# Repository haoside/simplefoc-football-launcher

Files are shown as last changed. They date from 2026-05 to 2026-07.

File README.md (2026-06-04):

# SimpleFOC Football Launcher

基于 SimpleFOC 的三无刷电机足球发射控制系统。

P0 目标：完成三路电机速度闭环、三轮同步预转、单次稳定射出标准 5 号足球，并具备基础安全保护。P0 明确为单球手动上球，不做多球管道/球仓/闸门。

## Project Goal

构建一套用于足球训练的三轮摩擦发射原型，通过三路 BLDC 独立调速与转速差控制，验证足球的速度、方向与旋转控制能力。

## P0 Scope

- 单电机 SimpleFOC 闭环稳定
- 三电机独立速度闭环
- 三轮同步预转
- 手动上球口 / 发射位球检测
- 单次稳定射出标准 5 号足球
- 急停 / 过流 / 堵转 / 过热保护
- 足球场地可移动底盘，电池供电优先
- 自动捡球接口预留（不实现机构）
- 面向专业足球运动员边路 `15~20m` 长传训练需求

## Out of Scope

- 自动瞄准
- 视觉识别
- 连续供球 / 多球仓 / 供球管道 / 闸门
- 自动捡球机构实现（仅预留接口）
- 高速发射
- 远程无人值守
- HA / Matter 接入

## Default Technical Direction

- 布局：`120° 均布三轮`
- 控制架构：`1 个上位控制板 + 3 个独立电机控制节点`
- 上位控制板：`ESP32-S3`
- 电机控制节点：`B-G431B-ESC1 ×3`
- Control Framework：`SimpleFOC`
- Motor：优先带 Hall 的 `6374 BLDC`，`170~190KV`
- Node 方案：P0-A 台架每个轮子 1 块 `B-G431B-ESC1`；P0-B 实球发射需切到高电流 SimpleFOC 驱动，不能把 B-G431B-ESC1 直接当最终动力板
- Feedback：P0 优先 Hall，增强方案可切 `AS5048A`
- Power：P0-A 低速台架按 `24V`；P0-B 现场按 `24V LiFePO4 40~60Ah` 与工程复核后的保护链路
- Control Target：P0 先做 `速度控制`

## P0 Milestones

1. 单电机闭环跑通
2. 三电机独立闭环跑通
3. 发射位球检测 + 发射状态机跑通
4. 单次低速稳定射球
5. 故障保护停机

## Suggested Repository Layout

```text
/docs
  P0_TECH_PLAN.md
  BOM_DRAFT.md
  INTERFACES.md
  CONNECTION_SCHEME.md
  CONNECTION_DIAGRAM.md
  FIRMWARE_MODULES.md
/firmware
  common/
  host-esp32s3/
  motor-node-g431/
/hardware
  README.md
  host-esp32s3/
  motor-node-g431/
  PCB_RULES.md
  HOST_PCB_LAYOUT.svg
  MOTOR_NODE_PCB_LAYOUT.svg
```

## Safety

> 该项目涉及高速旋转部件和射出机构，P0 仅允许低速测试。

- 必须先做低速测试
- 发射方向禁止站人
- 必须有物理急停按钮
- 必须安装摩擦轮防护罩
- 默认上电即安全空闲态
- 无人看护时禁止运行

## Status

当前阶段：`P0 方案冻结 / 硬件与固件拆分中`

## Bring-up

- `docs/FIRMWARE_BRINGUP_PLAN.md`
- `docs/FIRMWARE_BRINGUP_CHECKLIST.md`

- `docs/CAN_PROTOCOL_V1.md`
- `docs/FIRMWARE_COMM_LOOP.md`
- `docs/NODE_CONTROL_CHAIN.md`
- `docs/HOST_CONTROL_CHAIN.md`
- `docs/FAULT_SAFETY_CHAIN.md`
- `docs/HAL_ADAPTER_PLAN.md`
- `docs/HAL_INTEGRATION_STATUS.md`
- `docs/NODE_HAL_DATA_FLOW.md`
- `docs/PLATFORM_TEMPLATE_PLAN.md`
- `docs/HOST_TELEMETRY_V1.md`
- `docs/ARCH_DECISION_BG431B_ESC1.md`
- `docs/CODEGEN_SINGLE_BALL_HOST_V1.md`
- `docs/CODEGEN_BG431B_NODE_V1.md`
- `docs/BG431B_NODE_INSTANTIATION_V1.md`
- `docs/HOST_3NODE_INTEGRATION_DEMO_V1.md`
- `docs/DEBUG_GUIDE_V1.md`
- `docs/NODE_DEBUG_OUTPUT_V1.md`
- `docs/HOST_DEBUG_COMMANDS_V1.md`
- `docs/CURVE_BALL_CONTROL_V1.md`
- `docs/HOST_DEBUG_WHEEL_JOG_V1.md`
- `docs/PRACTICAL_CURVE_PASS_PRESETS_V1.md`
- `docs/SHORT_GUIDE_TUBE_V1.md`
- `docs/HOST_PRESET_COMMANDS_V1.md`
- `docs/SHORT_GUIDE_TUBE_TEST_MATRIX_V1.md`
- `docs/P0_AB_TEST_LOG_TEMPLATE_V1.md`
- `docs/ENVIRONMENT_SIM_PARAMS_V1.md`
- `docs/ENVIRONMENT_SIM_TEST_MATRIX_V1.md`
- `docs/P0_FIELD_TEST_LOG_TEMPLATE_V2.md`
- `docs/sim/ENVIRONMENT_TUNING_RECOMMENDATIONS_V1.md`
- `docs/HOST_WIND_PRESETS_V1.md`
- `docs/HOST_ENV_PROFILES_V1.md`
- `docs/HOST_ENV_COMMANDS_V1.md`
- `docs/HOST_ENV_PRESET_COMMAND_MATRIX_V1.md`
- `docs/OPERATOR_QUICK_CARD_V1.md`
- `cad/3d-print/short-guide-tube-v1/short_guide_tube_v1.scad`
- `docs/mechanical/SHORT_GUIDE_TUBE_DRAWING_V1.md`
- `cad/sheet-metal/motor-mount-plate-v1/motor_mount_plate_v1.scad`
- `docs/mechanical/MOTOR_MOUNT_PLATE_DRAWING_V1.md`
- `docs/mechanical/CAD_EXPORT_GUIDE_V1.md`
- `docs/mechanical/MANUFACTURING_PRIORITY_V1.md`
- `docs/mechanical/PRE_FAB_CHECKLIST_V1.md`
- `docs/mechanical/EXPORT_FILE_CHECKLIST_V1.md`
- `docs/mechanical/FILE_VERSION_MATRIX_V1.md`

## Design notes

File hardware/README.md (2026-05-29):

# Hardware Design Package v1

当前仓库已补硬件设计基线，用于进入原理图与 PCB 设计阶段。

## 文件
- `host-esp32s3/HOST_SCHEMATIC.md`
- `motor-node-g431/MOTOR_NODE_SCHEMATIC.md`
- `host-esp32s3/HOST_COMPONENT_LIST.md`
- `motor-node-g431/MOTOR_NODE_COMPONENT_LIST.md`
- `motor-node-g431/MOTOR_NODE_SUBCIRCUITS.md`
- `PCB_RULES.md`
- `HOST_PCB_LAYOUT.svg`
- `MOTOR_NODE_PCB_LAYOUT.svg`
- `pinout/HOST_PINOUT.md`
- `pinout/MOTOR_NODE_PINOUT.md`
- `pinout/CONNECTOR_TABLE.md`
- `pinout/HOST_NETS.csv`
- `pinout/MOTOR_NODE_NETS.csv`
- `host-esp32s3/HOST_NET_BY_NET.md`
- `motor-node-g431/MOTOR_NODE_NET_BY_NET.md`
- `PCB_LAYOUT_CONSTRAINTS.md`
- `host-esp32s3/HOST_SCHEMATIC_PAGES.md`
- `motor-node-g431/MOTOR_NODE_SCHEMATIC_PAGES.md`
- `SCHEMATIC_PAGE_INTERFACES.md`
- `host-esp32s3/HOST_FOOTPRINT_GUIDE.md`
- `motor-node-g431/MOTOR_NODE_FOOTPRINT_GUIDE.md`
- `FIRST_SPIN_BRINGUP.md`

## 当前设计策略
- Host 与 Motor Node 分板
- Motor Node 一板一电机
- CAN 作为 Host ↔ Node 总线
- 24V P0 联调，预留 36V 升级
- 急停硬件切驱动使能/主回路

## 下一步
1. 按上述网表与接口在 KiCad 建原理图
2. 先完成 Host 板与单个 Motor Node 板
3. 用单电机闭环先验证功率级与 Hall 反馈

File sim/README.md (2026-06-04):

# P0 Simulation: 3-BLDC Football Launcher

## Goal

Validate the first-order mapping:

```text
wheel1/2/3 RPM -> launch speed / spin / curve / landing point
```

This is a lightweight numerical model for parameter screening. It is not CFD, FEA, or final system validation.

## Frozen geometry

- 3 friction wheels in 120° distribution
- wheel1 @ 12:00
- wheel2 @ 4:00
- wheel3 @ 8:00
- standard size-5 football: 0.22 m diameter, 0.43 kg
- nominal wheel diameter: 0.11 m

## Run

```bash
python3 sim/football_launch_model.py
```

## Outputs

- recommended wheel RPMs for:
  - straight pass
  - light curve assist pass
  - standard curve assist pass
- estimated launch speed
- estimated spin rate
- estimated range and lateral offset
- rough current risk flag based on RPM/ramp

## Calibration needed on real machine

1. Actual wheel surface speed vs. measured ball exit speed.
2. Effective friction coefficient for wheel rubber + football surface.
3. Best preload window between 5–15 mm.
4. Actual curve strength vs. `spinBiasRpm`.
5. Current peak during 4/5/6 s spin-up ramps.

## P0 acceptance use

Use the model to choose first safe RPM presets before field tests. Then update the model constants from measured data.

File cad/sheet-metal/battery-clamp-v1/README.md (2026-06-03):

# Battery Clamp v1

## Purpose
Retaining top clamp for 24V LiFePO4 battery in lower bay.

## Key dimensions
- Strap plate: 260 mm x 35 mm x 4 mm
- Mount holes: 2 x 6.0 mm
- Center relief slot: 120 mm x 12 mm
- Material: 5052 / 6061, 4 mm

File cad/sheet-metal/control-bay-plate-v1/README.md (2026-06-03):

# Control Bay Plate v1

## Purpose
Mounting plate for ESP32-S3, three B-G431B-ESC1 nodes, and CAN/terminal area.

## Key dimensions
- Plate: 250 mm x 180 mm x 4 mm
- Corner mount holes: 4 x 5.5 mm
- Board standoff holes: mixed 3.2 mm / 4.0 mm provisional
- Material: 5052 / 6061, 4 mm

## Notes
- Hole positions are provisional for P0 packaging.
- Must be rechecked against actual B-G431B-ESC1 board outline after purchase.

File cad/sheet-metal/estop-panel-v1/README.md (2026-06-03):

# E-Stop Panel v1

## Purpose
Front-right mounting panel for emergency stop button.

## Key dimensions
- Plate: 100 mm x 80 mm x 3 mm
- E-stop hole: 22.5 mm
- Mount holes: 4 x 5.0 mm
- Material: 5052 / 6061, 3 mm

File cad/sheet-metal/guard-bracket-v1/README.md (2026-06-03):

# Guard Bracket v1

## Purpose
Flat bracket set for supporting the transparent PC guard cover.

## Key dimensions
- Main bracket plate: 220 mm x 40 mm x 4 mm
- Mount holes: 4 x 5.5 mm
- Guard holes: 3 x 4.5 mm
- Material: 5052 / 6061, 4 mm

## Notes
- P0 favors flat-plate manufacturability first.
- Final bend / standoff strategy may be added after frame spacing is confirmed.

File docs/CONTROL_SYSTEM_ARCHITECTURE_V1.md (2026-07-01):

# 控制系统架构 V1 — 车载显示器 + 控制器

> 状态：V1 初版
> 作者：全栈工程师
> 触发：PM 重新分配任务（2026-07-01）
> 关联：DISPLAY_UI_WIREFRAME_V1（设计师交付）
> 目标：可落地的车载人机控制方案，不只是展示图

---

## 0. 范围与边界

**包含**：
- 主控硬件选型（3 档对比）
- 显示器、摄像头、电机控制、推进控制、电源
- 软件模块划分
- 屏幕显示字段
- 控制输入设计
- 数据流 + MVP 清单

**不包含**（后续 V2+）：
- 具体 PCB 设计
- 真实 Gazebo / 仿真环境
- 安全认证（CE/UL）
- 详细成本报价

---

## 1. 硬件架构

### 1.1 主控选型（三档对比）

| 维度 | ESP32-S3 | Raspberry Pi 4B | Jetson Nano |
|---|---|---|---|
| CPU | Xtensa LX7 双核 240 MHz | Cortex-A72 4 核 1.5 GHz | Cortex-A57 4 核 1.43 GHz + 128 CUDA |
| RAM | 512 KB SRAM + 8 MB PSRAM | 4 GB LPDDR4 | 4 GB LPDDR4 |
| 实时性 | ⭐⭐⭐ 硬实时 | ⭐⭐ 软实时（Linux） | ⭐⭐ 软实时（Linux）|
| 视觉推理 | ❌ 跑不动 ML | ⭐⭐ 基础 CNN/TF-Lite | ⭐⭐⭐ GPU 推理 |
| 视频输入 | 1× 摄像头 (小分辨率) | 2× CSI / USB | 2× CSI / USB |
| 显示器输出 | SPI/8080（小型）| HDMI 2× | HDMI + DP |
| 功耗 | 0.5 W | 5 W | 10 W |
| 价格 | ¥20 | ¥300 | ¥800 |
| 实时控制 3× 电机 | ⭐⭐⭐ 直接 PWM | ⭐⭐ 需要 RT-PREEMPT | ⭐⭐ 需要 RT-PREEMPT |
| **MVP 推荐** | ✅ **选这个** | 备选 | 长期升级 |

**MVP 选 ESP32-S3**：
- 硬实时满足 3 电机 1kHz 控制环
- 功耗低、发热少、车载电池友好
- 摄像头 + 视觉推理可通过外接 USB 摄像头 + 上传至云/手机
- 显示器接 SPI 5寸触摸屏（够用）

**长期升级路径**：
- ESP32 → Pi 4B（加本地视觉）
- Pi 4B → Jetson Nano（加 GPU 视觉）

### 1.2 显示器

| 选项 | 规格 | 优势 | 劣势 |
|---|---|---|---|
| **5 寸 HDMI 触屏** | 800×480 | 便宜、体积小 | 户外可视性一般 |
| 7 寸 HDMI 触屏 | 1024×600 | 大、信息多 | 体积大 |
| 7 寸高亮屏 | 1000 nits | 户外强光可读 | 贵、发热大 |
| **车载工业屏** | 7-10 寸，IP65 | 抗振防水 | ¥2000+ |

**MVP 选 5 寸 HDMI 触屏**（¥80-150）+ 遮光罩（户外）。

### 1.3 摄像头

| 方案 | 用途 | FPS | 延迟 |
|---|---|-----|---|
| USB 摄像头 (Logitech C270 等) | 球路捕捉 | 60 | 50 ms |
| Pi CSI 摄像头 (IMX219) | 球路捕捉 + 嵌入式 | 30 | 30 ms |
| 工业相机 (FLIR/Point Grey) | 高速捕捉 | 120+ | <10 ms |
| **手机 + WiFi 上传** | 慢速捕捉 | 30 | 200 ms |

**MVP 选 USB 摄像头**（最便宜、足够 MVP 验证）。

### 1.4 电机控制（3 路）

| 部件 | 选型 |
|---|---|
| 电机 | 3× 6374 BLDC（外转子当滚轮）|
| 驱动器 | 3× **SimpleFOC B-G431B-ESC1**（已选）|
| 通信 | SPI 或 CAN 总线 → 主控 ESP32 |
| 编码器 | AS5048A 磁编码器（已选）|
| 闭环 | FOC 扭矩/速度环，1 kHz |

**理由**：SimpleFOC 是项目已选方案，硬件 BOM 已确定，V1 沿用。

### 1.5 推进控制（气压主线）

| 部件 | 选型 |
|---|---|
| 气源 | 8 bar 压缩机 或 20L 钢瓶 |
| 储气罐 | 5-20L 不锈钢（带爆破片）|
| 电磁阀 | 12V 大流量两位三通阀（响应 <30 ms）|
| 压力传感器 | 0-1 MPa 模拟输出 |
| 阀门 | 手动截止阀（安全）|
| 爆破片 | 1.2× 工作压力（10 bar）|
| 泄压阀 | 1.1× 工作压力（9 bar）|
| 球挡位置 | 红外对射传感器（检测球到位）|

### 1.6 电源

| 用电器 | 电压 | 电流 | 电源 |
|---|---|---|---|
| 主控 ESP32 | 5V | 0.5A | 5V DC-DC |
| 显示器 | 12V | 1A | 12V DC-DC |
| 3× ESC | 12-24V | 3× 30A 峰值 | 锂电池 24V |
| 电磁阀 | 12V | 1A | 12V DC-DC |
| USB 摄像头 | 5V | 0.5A | 5V |
| 风扇（散热）| 12V | 0.2A | 12V |

**主电源**：24V 锂电池组（10Ah 起）→ DCDC 隔离
- 控制电源（5V/12V）与动力电源（24V）**物理隔离**
- 加 TVS 防浪涌、保险丝

---

## 2. 软件模块

### 2.1 模块划分

```text
control_system/
├── main/                # 主控 ESP32 固件
│   ├── main.cpp         # FreeRTOS 主循环
│   ├── motor_ctrl.cpp   # 3× FOC 闭环控制
│   ├── valve_ctrl.cpp   # 电磁阀 + 压力传感器
│   ├── safety.cpp       # 急停 / 互锁
│   └── comm.cpp         # CAN/SPI 主从通信
├── vision/              # 视觉（Pi 或 ESP32-S3 USB）
│   ├── capture.cpp      # 摄像头采集
│   ├── track.cpp        # 球路识别（OpenCV）
│   └── predict.cpp      # 轨迹预测
├── ui/                  # 显示器界面（PyQt 或 LVGL）
│   ├── main_screen.py   # 主控首页
│   ├── arc_screen.py    # 弧线模拟页
│   ├── param_screen.py  # 参数调节页
│   └── diag_screen.py   # 诊断页
├── comm/                # 主从通信协议
│   ├── can_proto.md     # CAN 消息定义
│   └── serial_proto.md  # 串口消息定义
├── config/              # 配置
│   ├── mvp_params.yaml  # MVP 默认参数
│   └── presets/         # 发射预设
└── sim/                 # 仿真接口
    ├── trajectory.py    # 轨迹计算
    └── mux.py           # 3 电机混合
```

### 2.2 主控 ESP32 任务（FreeRTOS）

```c
// 任务优先级（数字越大越高）
void setup() {
  // Task 1: 电机控制循环 1kHz，优先级 10
  xTaskCreate(motor_ctrl_loop, "motor", 4096, NULL, 10, NULL);
  // Task 2: 阀门触发（紧急），优先级 12
  xTaskCreate(valve_trigger, "valve", 2048, NULL, 12, NULL);
  // Task 3: 通信接收，优先级 8
  xTaskCreate(comm_rx, "comm", 2048, NULL, 8, NULL);
  // Task 4: 安全监控，优先级 15（最高）
  xTaskCreate(safety_monitor, "safety", 1024, NULL, 15, NULL);
  // Task 5: 状态上报，优先级 5
  xTaskCreate(status_report, "status", 2048, NULL, 5, NULL);
}
```

### 2.3 显示器 UI（PyQt / LVGL）

**MVP 选 LVGL**（轻量，可在 ESP32-S3 上直接跑）：
- C 语言，资源占用小
- 支持触摸屏
- 可在 Pi 上用 Python binding

**完整版可换 PyQt**（在 Pi 4B 上）：
- Python 生态丰富
- 集成 OpenCV 视觉处理

### 2.4 视觉处理（轨迹捕捉）

```python
# vision/track.py 伪代码
def detect_ball_in_frame(frame):
    """在单帧中检测球位置（HSV 阈值 + 轮廓）"""
    hsv = cv2.cvtColor(frame, cv2.COLOR_BGR2HSV)
    mask = cv2.inRange(hsv, BALL_HSV_LOW, BALL_HSV_HIGH)
    contours, _ = cv2.findContours(mask, ...)
    if contours:
        largest = max(contours, key=cv2.contourArea)
        return cv2.minEnclosingCircle(largest)
    return None

def track_trajectory(frames):
    """从多帧提取球位置，滤波后输出轨迹"""
    positions = []
    for f in frames:
        p = detect_ball_in_frame(f)
        if p:
            positions.append(kalman_filter(p))
    return fit_parabola(positions)
```

---

## 3. 屏幕显示内容（与 UI Wireframe 对齐）

### 3.1 主控首页字段

| 字段 | 数据源 | 刷新率 |
|---|---|---|
| `mode` | 用户选择 | 触发时 |
| `launch_ready` | 状态机 | 100 ms |
| `safety_locked` | 物理急停 + 软件锁 | 10 ms |
| `emergency_stop` | GPIO + 软件 | 10 ms |
| `battery_percent` | ADC | 1 s |
| `battery_voltage` | ADC | 1 s |
| `temperature` | DS18B20 | 5 s |
| `pressure` | 模拟输入 | 100 ms |
| `propulsion_type` | 配置文件 | 启动时 |
| `valve_delay_ms` | 实测 | 1 s |
| `piston_force` | 编码器 | 100 ms |
| `motor_a/b/c_rpm` | FOC 反馈 | 100 ms |
| `motor_a/b/c_temp` | NTC | 1 s |
| `camera_status` | OpenCV | 1 s |
| `camera_fps` | 帧率计数器 | 1 s |
| `vision_confidence` | 检测分数 | 100 ms |

### 3.2 弧线页字段

| 字段 | 公式/来源 |
|---|---|
| `predicted_landing_x` | 物理模型（g, v0, angle）|
| `predicted_landing_y` | 物理模型 + Magnus |
| `actual_landing_x` | 视觉检测（球落点像素 → m）|
| `actual_landing_y` | 视觉检测 |
| `distance_error` | abs(pred - actual) |
| `lateral_error` | abs(pred_y - actual_y) |
| `landing_zone_heatmap` | 历史落点 2D 直方图 |
| `wind_estimate` | 多帧位移 → 速度差 |

### 3.3 参数页字段

| 参数 | 范围 | 单位 | 默认 |
|---|---|---|---|
| `motor_a_rpm` | 0-5000 | rpm | 2500 |
| `motor_b_rpm` | 0-5000 | rpm | 2500 |
| `motor_c_rpm` | 0-5000 | rpm | 2500 |
| `pressure` | 0-10 | bar | 8 |
| `valve_delay` | 0-100 | ms | 12 |
| `piston_force` | 0-100 | % | 75 |
| `curve_strength` | -50 to +50 | % | 0 |
| `topspin_strength` | -50 to +50 | % | 0 |

### 3.4 诊断页字段

| 字段 | 含义 | 颜色 |
|---|---|---|
| `system_status` | 整体 | 绿/黄/红 |
| `motor_a_temp` | 电机温度 | 绿<60°C / 黄<80°C / 红>80°C |
| `motor_rpm_drift` | RPM 偏差 % | <5%绿 / <10%黄 / >10%红 |
| `pressure_leak` | 压降速率 bar/s | <0.05 绿 |
| `valve_response_ms` | 阀门开闭时间 | <30 绿 |
| `battery_voltage` | 电池电压 | >22V 绿 |
| `cpu_temp` | 主控温度 | <70°C 绿 |
| `system_errors[]` | 错误码列表 | 详情面板 |

---

## 4. 控制输入

### 4.1 输入方式

| 输入 | 用途 | 优先级 |
|---|---|---|
| 触摸屏 | 主要调节 | MVP |
| 实体旋钮 ×2 | 备用调节（戴手套） | 第二阶段 |
| 物理急停按钮 | 安全（硬急停） | **必须** |
| 物理模式旋钮 | 模式快速切换 | MVP |
| 手柄/遥控 | 远距离发射 | 可选 |
| 语音 | 解放双手 | 不推荐（噪音） |

### 4.2 安全互锁

```c
// 发射触发前必检
bool launch_check() {
    return pressure_ok()        // 气压 ≥ 设定值 ±5%
        && motors_synced()      // 3 电机 RPM 在 ±5% 范围
        && ball_loaded()        // 球挡传感器触发
        && safety_unlocked()    // 物理解锁
        && !emergency_stop()    // 急停未触发
        && camera_ready()       // 摄像头就绪
        && no_errors();         // 无系统错误
}
```

### 4.3 急停链路

```text
[物理急停] → [硬件切断电磁阀电源]
         → [GPIO 中断到主控]
         → [电机控制 0 PWM]
         → [UI 全屏红色]
         → [需人工复位]
```

**急停是硬切断**，不依赖软件。

---

## 5. 数据流图

```text
                       视觉捕捉
                          ↓
  摄像头 → Pi/Jetson ──→ 落点检测
       (USB/CSI)         ↓
                    实际落点 (x,y)
                          ↓
  物理参数 ───→  仿真引擎  ───→  预测落点
  (RPM, 压力)    (Python)        (x,y)
                          ↓
                  偏差 = 实际 - 预测
                          ↓
                  ┌────────┴────────┐
                  ↓                 ↓
              UI 显示          参数回填
          (车载显示器)    (推荐新 RPM/压力)
                              ↓
                          ESP32 主控
                              ↓
              ┌───────┬───────┬───────┐
              ↓       ↓       ↓       ↓
            电机 A  电机 B  电机 C  电磁阀
              (6374) (6374) (6374)   (气压)
              ↓       ↓       ↓       ↓
            can    can    can    球被发射
              └───────┴───────┘
                  ↓
                 球
```

---

## 6. MVP 版本清单

### 6.1 MVP V1.0（4 周内）

| 项目 | 描述 | 状态 |
|---|---|---|
| 硬件 | ESP32-S3 + 3× ESC + 5寸触屏 + USB 摄像头 | 采购 |
| 控制 | 3 电机 1kHz 闭环 + 阀门触发 | 实现 |
| 安全 | 物理急停 + 气压互锁 | 实现 |
| UI | LVGL 4 屏（首页/弧线/参数/诊断）| 实现 |
| 视觉 | 球路捕捉（简单阈值）| 简化 |
| 通信 | USB 串口（PC 调试）| 简化 |

### 6.2 V1.1（4-8 周）

- Pi 4B 替代 ESP32-S3（加本地视觉）
- 完整 4 屏 UI（PyQt）
- 历史发射记录数据库
- 预设管理

### 6.3 V2.0（8-12 周）

- Jetson Nano 升级
- 完整视觉推理（球速、落点预测）
- 自动参数校正
- 多发射器联网管理

---

## 7. 验收标准

按 PM 要求：

| 标准 | 回答 |
|---|---|
| 1. 人怎么操作 | 触摸屏 + 旋钮 + 急停。模式按钮 → 确认 → 装球 → 发射。详情见 UI Wireframe |
| 2. 机器怎么执行 | ESP32 → FOC ESC → 3 电机 + 电磁阀。闭环 1kHz。阀门响应 <30ms |
| 3. 球路怎么被预测/反馈 | 物理模型（抛物 + Magnus）预测 + 摄像头识别实际 → 偏差 → UI |
| 4. 异常怎么停机 | 物理急停硬切断 + 软件互锁 → 全屏红 → 诊断页 → 复位 |
| 5. 切回推进结构 | 气压主线（轴向）+ 三电机控旋，控制器对应有 推进源切换 + 三电机 RPM 控制 |

---

## 8. 与 UI Wireframe 的接口

按设计师 `DISPLAY_UI_WIREFRAME_V1` 的字段清单：

```python
# ui/interface.py 字段
@dataclass
class UIData:
    # Mode
    mode: str                           # "STRAIGHT" / "LEFT_CURVE" / ...
    launch_ready: bool
    safety_locked: bool
    emergency_stop: bool

    # Pressure
    pressure_mpa: float
    propulsion_type: str                # "pneumatic" / "tangent_friction"
    valve_delay_ms: float
    piston_force_pct: float

    # Motors
    motor_a_rpm: int
    motor_b_rpm: int
    motor_c_rpm: int
    motor_a_temp_c: float
    motor_b_temp_c: float
    motor_c_temp_c: float

    # Vision
    camera_status: str                  # "OK" / "ERROR" / "OFFLINE"
    camera_fps: float
    vision_confidence: float

    # Trajectory
    predicted_landing_x: float
    predicted_landing_y: float
    actual_landing_x: float
    actual_landing_y: float
    distance_error_m: float
    lateral_error_m: float

    # Power
    battery_percent: float
    battery_voltage: float
    system_errors: list[str]
```

主控（ESP32）和 UI（Pi 屏）通过 CAN 或 USB 串口交换 UIData。

---

## 9. 已知风险

| 风险 | 缓解 |
|---|---|
| ESP32 算力不够视觉 | MVP 用 USB 摄像头 + Pi 远端处理 |
| 5 寸屏户外可读性差 | 加遮光罩，后期换 7寸高亮 |
| 锂电池振动/温度 | 用工业级电池（带 BMS）|
| 电磁阀误触发 | 双路阀门 + 物理急停 + 软件互锁 |
| 视觉识别误判 | 加置信度阈值，低置信度禁用发射 |
| 急停响应时间 | 物理急停硬切断 < 10ms |

---

## 10. 交付物

- ✅ 本文档 `CONTROL_SYSTEM_ARCHITECTURE_V1.md`
- ⏭ `MVP_PARAMS_V1.yaml`（默认参数）
- ⏭ `CAN_PROTOCOL_V1.md`（如果需要）
- ⏭ `comm.proto`（主从通信协议）
- ⏭ `safety_checklist.md`（安全清单）

---

## 11. 变更日志

- V1：初版，2026-07-01，按 PM 重新分配任务交付

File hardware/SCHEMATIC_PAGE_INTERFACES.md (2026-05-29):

# 原理图分页页间接口表 v1

## Host 板页间接口
| Page | Export Nets |
|---|---|
| H1 Power | `VIN_24V`, `+5V`, `+3V3`, `PGND`, `GND` |
| H2 ESP32 Core | `CAN_TX`, `CAN_RX`, `SIG_TUBE`, `SIG_CHAMBER`, `SIG_EXIT`, `SIG_ESTOP`, `PWM_FEED`, `FEED_DIR`, `LED_STATUS`, `BUZZER_CTL`, `UART0_TX`, `UART0_RX` |
| H3 CAN/Debug | `CAN_H`, `CAN_L` |
| H4 Sensors | 输入页，主要消费传感器信号 |
| H5 Feed/Indicators | 执行器与指示器页 |

## Motor Node 板页间接口
| Page | Export Nets |
|---|---|
| M1 Power | `VIN_24V`, `VDRV`, `+3V3`, `PGND`, `AGND`, `GND` |
| M2 MCU Core | `PWM_U`, `PWM_V`, `PWM_W`, `DRV_EN`, `DRV_FAULT_N`, `HALL_A`, `HALL_B`, `HALL_C`, `ISENSE_A`, `ISENSE_B`, `VBUS_SENSE`, `TEMP_SENSE`, `CAN_TX`, `CAN_RX`, `SWDIO`, `SWCLK`, `NRST` |
| M3 Gate Driver | `GH_U/GL_U`, `GH_V/GL_V`, `GH_W/GL_W`, `SH_U`, `SH_V`, `SH_W` |
| M4 Power Stage | `PHASE_U`, `PHASE_V`, `PHASE_W`, `ISENSE_A`, `ISENSE_B` |
| M5 Sense | Hall / VBUS / TEMP 感知页 |
| M6 CAN | `CAN_H`, `CAN_L` |

## 命名规则
- 页间全局网统一用大写下划线风格
- 功率网与逻辑网不要混名
- `PGND / AGND / GND` 明确分开，单点策略在 PCB 实现

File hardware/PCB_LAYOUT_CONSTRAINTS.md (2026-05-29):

# PCB 布局关键约束 v1

## Host 板
### 1. 电源
- 24V 输入、保险、TVS、DCDC 放在板边同一区域
- Buck 高 di/dt 回路尽量小
- 5V 与 3.3V 分区明显

### 2. MCU / 通信
- ESP32-S3 天线朝外，周围净空
- CAN 收发器靠近 CAN 接口
- 调试口靠板边

### 3. 传感器 / 执行器
- 传感器口成排放置，便于线束
- 舵机/闸门驱动靠近接口，避免大电流绕行 MCU
- 急停反馈与状态灯放近边缘便于维护

## Motor Node 板
### 1. 功率区优先
- `VIN_24V -> DC Link -> Half Bridge -> Motor Connector` 路径最短
- Gate Driver 紧贴 MOSFET
- Bootstrap 电容紧贴 Driver 脚位

### 2. 采样优先
- Shunt Kelvin 采样单独引出
- `VBUS_SENSE` 远离开关节点
- 模拟采样线不穿越相线区

### 3. 控制 / 通信
- STM32G431 放在 Driver 边缘但远离功率热区
- CAN 收发器靠近接口
- SWD 靠板边
- Hall 接口远离三相输出端子

### 4. 热与机械
- MOSFET 散热铜皮充分
- 功率区预留散热片/风道空间
- 电机三相接口用大焊盘、大电流端子
- 板安装孔避免穿过敏感回流路径

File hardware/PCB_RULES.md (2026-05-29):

# PCB 设计规则 v1

## 1. 分板建议
- **Host 板** 与 **Motor Node 板** 分开
- 不做三路一体功率板，P0 先以可调试、可替换为优先

## 2. Host 板
- 建议 4 层：`Signal / GND / 3V3_5V / Signal`
- 传感器与 CAN 靠近连接器放置
- DCDC 与 ESP32 天线区隔离
- 天线下方与前方保持净空

## 3. Motor Node 板
- 建议 4 层起步：`Signal / GND / Power / Signal`
- 功率回路最短：MOSFET、Driver、Shunt 紧凑布置
- Hall、CAN、SWD 远离三相开关节点
- 模拟采样地与功率地单点汇接
- 母线电容紧贴功率级

## 4. 关键布局约束
- Driver 到 MOSFET Gate 走线短且对称
- Shunt 到 ADC/放大器 Kelvin 引出
- VBUS 分压靠近 MCU ADC 输入并加 RC 滤波
- FAULT/ENABLE 线远离相线
- CANH/CANL 差分并行走线

## 5. 安全
- 24V 输入、功率级、逻辑区明确分区
- 预留测试点：3V3、5V、24V、VBUS_SENSE、ISENSE、FAULT、CAN
- 急停不要只依赖 MCU，PCB 需支持外部硬切

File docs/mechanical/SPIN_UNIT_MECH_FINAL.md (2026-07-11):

# 弧线旋转单元 · 最终结构设计

> 最后更新：2026-07-11
> 状态：✅ 结构锁定

## 结构原理（三角结构）

三个 6374 BLDC 电机位于等边三角形的三个顶点。每个电机的轴延长线指向下一个电机方向，三根轴延长线 = 等边三角形的三条边。发射筒位于三角形中心，电机轴穿过筒体（3D 圆筒）。外转子圆筒面通过筒壁窗口接触球面。

## 几何关系（核心约束）

- 三电机位于等边三角形**三个顶点**
- 每个电机轴延长线指向下一个电机 → **三根轴 = 三角形三条边**
- 发射筒在三角形**中心**
- 轴穿过筒体（3D 圆筒，不是仅截面圆）
- 外转子圆筒面（电机最大旋转面）接触球面
- 三电机旋转方向一致

## 关键参数

| 参数 | 数值 | 说明 |
|---|---|---|
| 发射筒 | ID Φ220 × L300mm | 一体式，壁上开 3 个窗口 |
| 电机位置 | 靠近出口端 | 球先过通道，出口附近加旋 |
| 电机 | 6374 BLDC 140KV × 3 | 外转子直驱 |
| 电机布局 | 等边三角形三顶点 | 轴延长线 = 三角形边 |
| 电机固定 | 圆形端面 4(8) 螺孔 | 端面朝外固定到支架 |
| 旋转方向 | 三电机一致 | 同速=正旋，差速=弧线 |
| 壳面 | 外转子圆筒面 | 电机最大旋转面，接触球面 |

## 零件清单

| # | 零件 | 数量 | 说明 |
|---|---|---|---|
| ① | 一体发射筒 | 1 | 壁上开 3 个窗口让壳面伸出 |
| ② | 6374 BLDC | 3 | 140KV · Φ63 × L74mm |
| ③ | 支架 | 1 | 三角形框架，固定三个电机 |
| ④ | 螺丝 | 若干 | 端面固定电机到支架 |
| ⑤ | 保护挡板 | 3 | 旋转端面非接触防护 |

## 参考来源

- thisismax B-G431B-ESC1 + SimpleFOC 视频
- thisismax "Bluey Blaster" Ball Launch System
- Owner 手绘草图：电机轴延长线构成等边三角形

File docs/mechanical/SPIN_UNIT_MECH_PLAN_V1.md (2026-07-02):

# 弧线旋转单元 · 机械设计方案 v1

> 最后更新：2026-07-02
> 架构 pivot：动力与旋转解耦，本方案仅覆盖弧线旋转单元

## 设计输入

- 电机：6374 BLDC 140KV × 3，外转子直驱
- 布局：120° 均布，电机轴垂直于筒轴（径向安装）
- 筒内径：Φ220mm（标准 5 号球通过）
- 功能：三电机独立调速，同速=正旋，差速=弧线

## 关键尺寸

| 参数 | 数值 | 说明 |
|---|---|---|
| 发射筒内径 | Φ220mm | 5 号球直径 216-226mm |
| 发射筒外径 | Φ290mm | 含壁厚 |
| 发射筒长度 | 300mm | 含电机嵌入段 |
| 壁厚 | 待计算 | 需承受电机扭矩+球面接触力 |
| 外转子壳面 | Φ63 × 150mm | 嵌入筒壁，接触球面 |
| 窗口尺寸 | Φ70mm | 壳面伸入通道，含装配间隙 |
| 电机轴径 | 按6374规格 | 径向安装，垂直于筒轴 |

## 零件清单

| # | 零件 | 规格 | 数量 | 备注 |
|---|---|---|---|---|
| ① | 发射筒 | ID Φ220 × OD Φ290 × L300mm | 1 | 开3个Φ70窗口，120°均布 |
| ② | 6374 BLDC | 140KV · Φ63 × L74mm · 带Hall | 3 | 外转子壳面嵌入筒壁 |
| ③ | 电机固定座 | 适配6374安装孔 | 3 | 固定到筒壁外侧 |
| ④ | 三角支架 | 120°均布框架 | 1 | 包裹电机，连接筒壁 |
| ⑤ | 螺栓 | M3/M4 | 12+ | 每电机4点固定 |
| ⑥ | 轴承 | 按6374轴径 | 6 | 每电机2点支撑 |

## 结构原理

1. 发射筒水平放置，球从一端进入
2. 三个电机径向安装在筒壁外侧
3. 外转子壳面通过筒壁窗口伸入筒内
4. 壳面旋转时，接触点切向速度平行于筒轴
5. 三电机同速 → 球正旋（直线球）
6. 三电机差速 → 球弧线

## 待细化

- [ ] 筒壁壁厚强度计算
- [ ] 窗口周围加强方案（加厚/加筋）
- [ ] 支架材料选型（3D打印/钣金/CNC）
- [ ] 轴承型号确认
- [ ] 电机固定方式细化
- [ ] 防护罩设计
- [ ] 与发射动力单元的接口定义

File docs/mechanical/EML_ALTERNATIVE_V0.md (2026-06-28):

# 电磁弹射替代方案评估 V0

> 状态：初稿（替代方案调研，非主线）
> 触发：owner 询问"电磁弹射能否替代气压"
> 关联：PROPULSION_ARCHITECTURE_REVIEW_V1.md（气压主线）

---

## 0. 电磁弹射（EML）候选类型

| 类型 | 原理 | 足球适配性 |
|---|---|---|
| 线圈炮（Coilgun / Gauss） | 多级同步线圈磁场加速 | ❌ 极难，足球质量 100× 典型弹丸 |
| 直线感应电机（LIM） | 行波磁场推力 | ⚠ 可行但效率低、控制复杂 |
| 轨道炮（Railgun） | 洛伦兹力直接推 | ❌ 极危险、磨损大、不适合球 |
| 同步直线电机（PMLSM） | 永磁+线圈同步 | ⚠ 可行但线圈复杂 |

---

## 1. 能量需求估算

球目标：220mm, 430g, 50m 射程 → 出膛速度 v ≈ 25 m/s

```
KE = 0.5 × m × v²
   = 0.5 × 0.43 × 25²
   = 134 J  ← 球获得的动能
```

**EML 系统总能耗**：
- 线圈炮典型效率 1-5%
- 输入能量 = 134 / 0.02 ≈ **6700 J**
- LIM/PMLSM 效率 30-60%
- 输入能量 ≈ **225-450 J**

**对比气压（基准）**：
- 8 bar / 20 L 气罐内能 = P × V = 8e5 × 0.020 = **16000 J**（理论）
- 实际有效做功 ≈ 5-15%（阀门 + 摩擦 + 漏气）
- 球获得 ≈ 800-2400 J 等效，远超 134 J → 8 bar 完全够用

---

## 2. EML 用于足球的具体难点

### 2.1 质量 / 尺寸失配
- 标准线圈炮弹丸：1-50 g
- 标准 5 号足球：430 g（**8-400× 重**）
- 足球直径 220 mm 需要巨大的线圈孔径
- 线圈电感 L 随面积增大 → 电流上升慢 → 加速力下降
- 结论：**同等速度下需要 8-400× 的磁场能量**

### 2.2 电容 / 储能
- 6700 J 电容储能 ≈ 1-2 kg 大电容（400V, 几十 mF）
- 充电时间数秒 → 不能快速连发
- 高电压（>300V）危险

### 2.3 安全
- 电容放电瞬间电流 >10 kA
- 强磁场对心脏起搏器、磁性物危险
- 线圈炮失败模式（弹丸卡住、放电短路）→ 烧毁

### 2.4 磨损
- 足球不像金属弹丸，无导轨约束
- 球在管内无固定电磁锚点，会被磁场反弹/偏转
- 必须有机械导轨（限制电磁优势）

### 2.5 控制
- 球质量大、运动慢 → 需要长加速段（>500mm）
- 多级线圈需要精确同步触发（μs 级）
- 闭环反馈（球位置/速度）极难

---

## 3. 与气压方案对比

| 维度 | 电磁弹射 | 压缩空气 |
|---|---|---|
| 球 25 m/s 所需储能 | 6700 J（输入） | 16000 J（理论）/ 200-500 J（有效） |
| 设备复杂度 | 高（电容 + 线圈 + 触发） | 中（罐 + 阀 + 管） |
| 安全等级 | **高危**（>300V, kA 级电流） | **中危**（<8 bar, 标准件） |
| 成本 | 高（电容/线圈/IGBT） | 低（标准气动件） |
| 维护 | 难（电气） | 易（机械） |
| 连续发射 | 受电容充电限制 | 受储气量限制 |
| 旋转控制 | 可调线圈时序 | 单独电机模块 |
| 商业参考 | 极少（仅电磁炮爱好）| **多**（FORZA / Jug's 等）|
| 50m 目标可行性 | 可行但极端 | ✅ 已验证可行 |

---

## 4. 结论

### 4.1 电磁弹射 P0 不推荐

理由：
- **能**在原理上替代气压
- 但**成本、安全、维护、复杂度**全面劣于气压
- 仅在**没有气源 / 完全电磁化**的特殊场景下有意义
- P0（首版 / 训练场 50m 验证）首选仍是气压

### 4.2 何时考虑 EML

- 远期：电磁化发射阵列（无气源环境、太空、月球基地）
- 玩具/小型球：低压线圈炮（<1J 储能）
- 教学演示：展示 Lorentz 力的应用

### 4.3 折中方案：LIM 短距离辅助

如果未来想做"无气源"版本：
- LIM 段 + 电磁预加速
- LIM 仅作短距离（<100mm）辅助
- 主推进仍靠气压或弹簧储能

---

## 5. 仿真口径（如果以后要做 EML）

```
EML 输入:
- 线圈匝数 N
- 线圈电流 I(t)
- 加速段长度 L_accel
- 球质量 m

EML 输出:
- 出膛速度 v_exit
- 加速时间 t_accel
- 储能 E_stored
- 系统效率 η
```

参考开源工具：openEMS（FDTD 电磁仿真）、FEMM（2D 磁场有限元）

---

## 6. 当前动作

P0 主线**不切换**，仍按气压方案推进：
1. Stage 1：5 bar PVC 纯气炮验证
2. Stage 2：8 bar 电磁阀 + 简单电控
3. Stage 3：加三电机控旋

EML 留作**远期调研备选**（不进入 P0）。

---

## 变更日志

- V0：初版，owner 询问后做替代方案对比，结论"不推荐 EML 替代气压进入 P0"

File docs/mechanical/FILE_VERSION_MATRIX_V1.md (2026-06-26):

# 文件版本管理表 v1

| 类别 | 文件 | 当前版本 | 备注 |
|---|---|---|---|
| 3D 打印 | short_guide_tube_v1.scad | v1 | 短导向筒 |
| 钣金 | motor_mount_plate_v1.scad | v1 | 电机安装板 |
| 钣金 | guard_bracket_v1.scad | v1 | 防护罩支架 |
| 钣金 | control_bay_plate_v1.scad | v1 | 控制仓安装板 |
| 钣金 | power_bay_plate_v1.scad | v1 | 电源仓安装板 |
| 钣金 | battery_clamp_v1.scad | v1 | 电池压板 |
| 钣金 | estop_panel_v1.scad | v1 | 急停面板 |
| 文档 | MANUFACTURING_FILESET_V1.md | v1 | 制造文件索引 |
| 文档 | CAD_EXPORT_GUIDE_V1.md | v1 | 导出规范 |
| 文档 | PRE_FAB_CHECKLIST_V1.md | v1 | 加工前复核 |
| 装配 CAD | outrunner_launch_tube_v1.scad | v1 | 端面固定发射筒，筒身开口，外转子直驱接触 |
| 文档 | OUTRUNNER_LAUNCH_TUBE_V1.md | v1 | 外转子直驱发射筒设计说明 |
| 渲染/三视图 | OUTRUNNER_LAUNCH_TUBE_THREE_VIEW_V1.svg | v1 | 发射筒三视图说明 |
| 装配 CAD | outrunner_launch_tube_v1_1.scad | v1.1 | 6354 外转子发射筒，2–3mm 可调压紧，防护罩孔位/加强肋补强 |
| 文档 | OUTRUNNER_LAUNCH_TUBE_V1_1.md | v1.1 | 外转子直驱发射筒 v1.1 设计说明 |
| 渲染/三视图 | OUTRUNNER_LAUNCH_TUBE_THREE_VIEW_V1_1.svg | v1.1 | 发射筒三视图说明 v1.1 |
| 文档 | MAINLINE_MODEL_ADJUSTMENT_V2.md | v2 | 主线并线检查、参数同步与工程验证入口结论 |
| 文档 | ENGINEERING_VALIDATION_V1_2.md | v1.2 | 工程验证总表、方法、通过标准、风险等级与失败修改路径 |

## 版本规则
- 尺寸修改：升小版本（v1 -> v2）
- 孔位/结构逻辑修改：直接升主版本（v1 -> v2）
- 采购件确认后再进入“rev-A”口径
| 文档 | MEASUREMENT_SHEET_6354_V1.md | v1 | 6354 实测接口记录表，用于锁外径/长度/端面孔距 |
| 文档 | PRELOAD_COUPLING_MATRIX_V1.md | v1 | 包胶厚度与压紧量联动矩阵，一阶风险筛选 |
| 文档 | SIM_VALIDATION_MAINLINE_V1.md | v1 | 仿真验证主线说明，明确当前推进口径转向仿真优先 |
| 数据 | SIM_SENSITIVITY_MATRIX_V1.csv | v1 | 仿真敏感度矩阵，记录 friction/preload 对输出的影响 |
| 装配 CAD | outrunner_embedded_launch_tube_v1_2.scad | v1.2 | 嵌入式 3 外转子发射圆管，45×45 单端安装，圆管出口为发射基准 |
| 文档 | OUTRUNNER_EMBEDDED_LAUNCH_TUBE_V1_2.md | v1.2 | 嵌入式发射圆管结构说明 |
| 文档 | ENGINEERING_SIMULATION_PLAN_V1_2.md | v1.2 | v1.2 几何干涉/运动包络/50m/RPM/180° 弧线仿真计划 |
| 渲染/三视图 | OUTRUNNER_EMBEDDED_LAUNCH_TUBE_V1_2.svg | v1.2 | 嵌入式发射圆管结构说明图 |
| 文档 | GEOMETRY_INTERFERENCE_REVIEW_V1_2.md | v1.2 | v1.2 主线并线几何干涉快速复核 |
| 装配 CAD | outrunner_embedded_short_tube_v1_2a.scad | v1.2a | 76mm 短圆管/短环，三外转子嵌入夹持，+Z 出口轴线为发射方向 |
| 文档 | OUTRUNNER_EMBEDDED_SHORT_TUBE_V1_2A.md | v1.2a | v1.2a 短圆管嵌入版结构说明 |
| 文档 | SHORT_TUBE_V1_2A_ENGINEERING_REVIEW.md | v1.2a | v1.2a 并线工程复核，覆盖短管导向/口袋干涉/旋转包络/45×45/出口轴线 |
| 装配 CAD | outrunner_embedded_short_tube_v1_2b.scad | v1.2b | 去除保护罩表达，突出三电机嵌入短发射管，发射方向按三电机合力方向 |
| 文档 | SIM_VISUALIZER_V10_RESULTANT_UPDATE.md | v10 | 仿真可视化改为三电机合力方向出球，无保护罩口径 |
| 装配 CAD | outrunner_embedded_tilted_tube_v1_2c.scad | v1.2c | 三电机倾斜嵌入短发射管，合力方向直接向上发射，无保护罩 |
| 文档 | SIM_VISUALIZER_V12_TILTED_DIRECT_LAUNCH_UPDATE.md | v12 | 仿真可视化改为三电机倾斜布置直接向上发射 |
| 装配 CAD | outrunner_embedded_tilted_roll90_tube_v1_2d.scad | v1.2d | 三电机倾斜布置整体翻转 90°，合力方向直接向上发射，无保护罩 |
| 文档 | SIM_VISUALIZER_V13_ROLL90_UPDATE.md | v13 | 仿真可视化改为三电机倾斜布置 roll 90° |
| 装配 CAD | outrunner_photo_ref_embedded_tube_v1_2e.scad | v1.2e | 参照实物图：中心短发射管开口，三电机嵌入发射管周向窗口，倾斜 roll 90° 后合力发射 |
| 文档 | SIM_VISUALIZER_V14_PHOTO_REFERENCE_UPDATE.md | v14 | 仿真可视化加入照片口径结构理解面板，强化三电机嵌入发射管 |
| 装配 CAD | outrunner_target_resultant_tube_v1_2f.scad | v1.2f | 初始合力方向直接锁定目标方向，A/B/C 差速只用于侧旋弧线 |
| 文档 | SIM_VISUALIZER_V15_TARGET_RESULTANT_UPDATE.md | v15 | 仿真可视化改为目标方向锁定初始合力，侧旋与瞄准解耦 |
| 装配 CAD | outrunner_integrated_tube_motor_mount_v1_2g.scad | v1.2g | 发射圆管兼三电机固定一体结构，贴近参考图橙色一体夹持件 |
| 文档 | INTEGRATED_TUBE_MOTOR_MOUNT_V1_2G.md | v1.2g | 圆管 + 三电机口袋 + 端压板 + 加强筋一体结构说明 |
| 文档 | SIM_VISUALIZER_V16_INTEGRATED_STRUCTURE_UPDATE.md | v16 | 仿真可视化加入一体固定结构截面和 3D 一体夹持件表达 |
| 装配 CAD | outrunner_integrated_tube_motor_mount_v1_2h.scad | v1.2h | 停止仿真扩展，专注圆管兼三电机固定一体结构：线束出口、工具空间、转子包络、分型线 |
| 文档 | INTEGRATED_TUBE_MOTOR_MOUNT_V1_2H_ENGINEERING.md | v1.2h | 一体结构工程细化说明，明确暂停 widget/仿真更新 |
| 装配 CAD | outrunner_photo_integrated_mount_v1_2i.scad | v1.2i | 参照图片细化一体结构：侧板圆孔、顶部压条、底部托架、线束/工具避让 |
| 文档 | PHOTO_REFERENCE_INTEGRATED_STRUCTURE_V1_2I.md | v1.2i | 从参考图提取圆管兼三电机固定一体结构要点 |

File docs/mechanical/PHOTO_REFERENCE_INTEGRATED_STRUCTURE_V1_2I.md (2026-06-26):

# Photo Reference Integrated Structure V1.2I

## 指令来源
用户补发参考图，当前继续暂停仿真更新，只改机械：

**发射圆管兼三电机固定一体结构，必须贴近图片。**

---

## 图片结构要点提取
从参考图抽象出的关键结构：

1. **中心圆管开口明显**
   - 圆管不是独立件，而是橙色一体结构的中心孔。
   - 电机座围绕圆管外壁生长。

2. **三电机不是外挂板固定**
   - 电机嵌在橙色打印件的口袋 / 卡座里。
   - 每个电机有侧向包络、底托、端部压板。

3. **侧板有圆形减重 / 工具孔**
   - 图中橙色侧板上有明显圆孔。
   - 这些孔不能理解成保护罩孔，而是减重、工具进入、观察/线束避让的一体结构孔。

4. **顶部桥接压条 / 螺丝排**
   - 图片中前侧电机上方有一条橙色桥接压条，并带黑色螺丝。
   - 该结构用于压住电机或固定端盖。

5. **底部托架 / 电机托台**
   - 电机下方有橙色托底，不是悬空安装。
   - 托架与圆管、侧板、加强筋连续成型。

6. **线束从口袋边缘引出**
   - 线束不能被一体座压死。
   - 必须预留后侧或下侧线槽。

---

## CAD 新增
新增文件：

- `cad/assembly/p0-single-ball-launcher-v3/outrunner_photo_integrated_mount_v1_2i.scad`

基于 v1.2h 继续机械细化，不更新仿真。

### 新增参数

```scad
show_photo_side_plates = true;
show_bridge_straps = true;
show_round_relief_holes = true;
show_lower_motor_shelf = true;
photo_side_plate_t = 8;
photo_side_plate_w = 78;
photo_side_plate_h = 108;
round_relief_d = 24;
round_relief_pitch = 42;
bridge_strap_w = 22;
bridge_strap_t = 9;
bridge_strap_len = 96;
strap_screw_d = 4.2;
lower_motor_shelf_t = 8;
lower_motor_shelf_w = 96;
lower_motor_shelf_d = 36;
```

---

## 本版新增结构

### 1. Photo-like cheek plate
新增每个电机口袋外侧的橙色侧板：

- 厚度 `8mm`
- 高度 `108mm`
- 宽度 `78mm`
- 与电机口袋和圆管一体

### 2. Round relief / tool holes
侧板加入双圆孔：

- 孔径 `24mm`
- 孔距 `42mm`

用途：
- 减重
- 工具进入
- 观察转子/间隙
- 线束避让预留

### 3. Bridge strap
每个电机上方新增桥接压条：

- 长度 `96mm`
- 宽度 `22mm`
- 厚度 `9mm`
- 三颗 `4.2mm` 螺丝孔占位

贴近图片中电机上方黑色螺丝压条。

### 4. Lower motor shelf
每个电机下方新增托台：

- 宽度 `96mm`
- 深度 `36mm`
- 厚度 `8mm`

用于表达图片中的电机底托，避免电机悬空。

---

## 当前工程判断
v1.2i 比 v1.2h 更贴近图片，但仍是结构占位版，下一步需要继续：

1. 把侧板圆孔与真实工具路径对齐
2. 桥接压条改成可拆压盖，而不是完全一体
3. 端部螺丝孔对齐真实 6354 端盖孔距
4. 线束出口按照片中的下侧/后侧路径固定
5. 输出三视图 SVG，给设计师按图继续修正

---

## 结论
当前机械主线：

**圆管开口 + 三电机口袋 + 侧板圆孔 + 顶部压条 + 底部托架 + 线束槽，全部并入同一个橙色一体固定结构。**

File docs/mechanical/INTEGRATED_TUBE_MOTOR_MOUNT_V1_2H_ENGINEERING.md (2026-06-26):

# Integrated Tube + Three Motor Mount V1.2H Engineering Focus

## 指令
停止继续更新仿真，主线切换为：

**专注改进发射圆管兼三电机固定一体结构。**

本版不改 widget、不扩展轨迹仿真，只推进机械一体件。

---

## 当前结构目标

参考图口径保持：

```text
中心短发射管 + 三个电机嵌入口袋 + 端面压板 + 加强筋 + 线束/工具避让 = 一体结构
```

不是：
- 外挂电机板
- 独立保护罩
- 圆管与电机座分离
- 单纯仿真展示件

---

## CAD 新增

新增文件：

- `cad/assembly/p0-single-ball-launcher-v3/outrunner_integrated_tube_motor_mount_v1_2h.scad`

v1.2h 基于 v1.2g，但进入工程结构细化。

### 新增参数

```scad
structure_only_focus = true;
show_wire_channels = true;
show_tool_access = true;
show_rotor_clearance = true;
rotor_clearance_min = 3.0;
wire_channel_w = 13;
wire_channel_h = 8;
wire_channel_len = 52;
tool_access_d = 11;
tool_access_offset = 22;
split_service_gap = 2.0;
```

---

## 结构改进点

### 1. 线束出口
每个电机口袋新增线束通道占位：

- 宽度：`13mm`
- 高度：`8mm`
- 长度：`52mm`

目的：
- 避免一体口袋把三相线夹死
- 给电机翻转 90° 后的出线留路径
- 后续可改成后侧缺口或侧向线槽

### 2. 工具进入空间
每个电机口袋新增工具孔/工具包络：

- 工具直径：`11mm`
- 偏移：`22mm`

目的：
- 给内六角/螺丝刀进入端面压板
- 避免口袋一体化后无法拆电机
- 为端压板螺丝维护留空间

### 3. 转子包络
新增外转子旋转包络显示：

```scad
motor_d + 2 * rotor_clearance_min
```

当前最小目标间隙：`3mm`

用途：
- 检查转子与口袋内壁
- 检查端压板
- 检查加强筋
- 检查线束通道附近是否干涉

### 4. 服务分型线
新增 `split_service_gap = 2.0mm` 的分型线标记。

用途：
- 暂时作为视觉标记
- 后续可转成可拆压盖 / 分体夹具
- 避免一体件不可装配

---

## 工程结论

v1.2h 不再扩展仿真功能，当前主线是机械结构闭环：

1. 发射圆管和三电机固定座一体化
2. 三个电机口袋贴近参考图
3. 端压板、加强筋、线束出口、工具空间必须并入一体结构
4. 转子包络和维护空间作为下一轮重点验证

---

## 下一轮建议

1. 把 6354 真实端面孔距参数化
2. 将端面压板做成可拆压盖，而不是完全一体封死
3. 根据线束实际方向确定左/右/后侧出线槽
4. 输出 2D 端面三视图 / SVG，给设计师做结构复核

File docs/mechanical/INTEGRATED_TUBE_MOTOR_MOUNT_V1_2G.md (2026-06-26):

# Integrated Tube + Three Motor Mount V1.2G

## 当前口径
按 owner 参考图收紧：

**发射圆管兼三电机固定一体结构，必须贴近图片。**

结构不再理解为：
- 独立圆管 + 外挂电机板
- 圆管外另加保护罩
- 电机通过分离支架临时靠近球道

当前主线理解为：

```text
中心短发射管 + 三个周向电机嵌入口袋 + 端面压板 + 加强筋 = 一个橙色一体夹持件
```

---

## 一体结构组成

### 1. 中心短发射管
- 保持短管 / 短环口径
- 中心开口作为球道
- 管壁外侧直接长出三电机口袋

### 2. 三电机嵌入口袋
- 3 个 6354 外转子沿圆管周向约 120° 分布
- 口袋与圆管外壁连续成型
- 内侧保留接触窗口，让外转子直接接触足球
- 电机不是外挂在外圈上

### 3. 端面压板
- 每个电机口袋两端有压板 / 端盖限位
- 端面螺丝孔用于固定电机或压紧件
- 端面压板并入一体橙色结构，不单独漂浮

### 4. 加强筋
- 圆管与电机口袋之间增加三角 / 矩形加强筋
- 加强筋负责抵抗电机压紧力、振动和侧旋反扭矩
- 加强筋布置需避开线束出口和工具进入空间

---

## CAD 文件
新增：

- `cad/assembly/p0-single-ball-launcher-v3/outrunner_integrated_tube_motor_mount_v1_2g.scad`

关键参数：

```scad
integrated_monocoque = true;
photo_like_orange_body = true;
target_resultant_locked = true;
station_roll_deg = 90;
launch_tilt_deg = 18;
```

---

## 仿真 / Widget 对齐
Widget v16 已加入：

- 照片口径一体结构理解
- 一体固定结构截面
- 3D 橙色夹持环 / 电机口袋 / 端压板 / 加强筋
- 合力方向仍直接锁定目标方向

---

## 工程待验证

1. **口袋互相干涉**
   - 三个电机口袋在 roll 90° 后是否互相碰撞

2. **转子包络**
   - 外转子旋转时与口袋、端压板、加强筋的最小间隙

3. **接触窗口**
   - 内侧窗口是否足够让包胶转子压到球面
   - 是否存在管壁遮挡接触带

4. **端面固定**
   - 端压板孔位能否接真实 6354 端面
   - M5 / M4 螺丝工具是否可进入

5. **线束出口**
   - 三电机线束在一体口袋中不能被夹死
   - 需要预留线槽或后侧缺口

6. **强度与制造**
   - 一体打印/加工件是否需要分件拆装
   - 加强筋是否影响装配顺序

---

## 当前结论
v1.2g 作为新的结构仿真口径：

**圆管和三电机固定座做成一体，贴近参考图；合力方向直接指向目标，A/B/C 差速只负责侧旋弧线。**

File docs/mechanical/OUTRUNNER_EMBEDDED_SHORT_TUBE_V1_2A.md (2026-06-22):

# OUTRUNNER_EMBEDDED_SHORT_TUBE_V1_2A

## 新基准收紧
按新图和产品经理提炼，v1.2a 把主线再收紧为：

- **中心是短圆管 / 短环**，不是长发射筒主体
- **3 个外转子围绕圆管环抱**，贴近管壁接触球
- **电机嵌入式 / 夹持式安装**，不是外侧外挂
- **发射方向仍以圆管出口轴线为准**

对应 CAD：
- `cad/assembly/p0-single-ball-launcher-v3/outrunner_embedded_short_tube_v1_2a.scad`

---

## 与 v1.2 的区别

### 1. 管体缩短
v1.2 仍偏“短发射圆管 + 嵌入电机”，但长度还像一个小筒。  
v1.2a 明确改为 **短圆管 / 短环基准**：

```scad
short_tube_len = 76;
```

这更接近图里的结构：
- 中心只有短导向段
- 电机主要围绕短环布置
- 出口方向由短圆管轴线定义

### 2. 电机不外挂
v1.2a 的电机站位统一为：
- 管壁嵌入口袋
- 背部 saddle
- 侧向夹持
- 单侧端面夹板

视觉和结构上都不再是“外挂电机模块”。

### 3. 发射方向明确
CAD 中用绿色箭头表达：
- `+Z` 为圆管出口方向
- 发射方向以圆管出口为准
- 三电机只负责加速/旋转，不改变出口轴线定义

---

## 当前保留参数

```scad
inner_d          = 232;
motor_d          = 63;
motor_len        = 54;
contact_sink     = 2.5;
contact_sink_min = 2.0;
contact_sink_max = 3.0;
main_mount_pitch = 45;
motor_flip_180   = true;
```

---

## 结构说明

### 中心短圆管
- 内径仍按 `232mm`
- 作用是定义球通过的中心通道与出口轴线
- 不是长筒导向，不承担长距离导向功能

### 三外转子嵌入
- 三个 6354 外转子 120° 环抱
- 外转子工作面进入球道 `2–3mm`
- 接触逻辑仍然是直接外转子 / 包胶接触球

### 嵌入式夹持安装
每个电机由三部分约束：
1. 管壁嵌入口袋
2. 背部 saddle 支撑
3. 单侧端面夹板

后续实测端面孔距后，只改端夹孔位参数，不改整体排布。

### 单端 45×45 固定
继续保留 owner 指定接口：
- 一端固定
- 4 螺丝
- 45×45 方阵
- 默认 M5 间隙孔

---

## 工程风险

1. **短圆管导向长度不足**
   - 优点：结构紧凑，符合图
   - 风险：球进入/离开时稳定性依赖三电机同步和入口姿态

2. **嵌入式电机散热更难**
   - 电机贴近管壁
   - 防护罩不能封死
   - 需要预留导风/散热开口

3. **夹持座与真实 6354 外形可能干涉**
   - 端面凸台
   - 线束出口
   - 螺钉头高度
   - 包胶外径

4. **50m 与 180° 弧线仍是仿真目标**
   - 结构已为仿真收紧
   - 但性能必须由转速、摩擦、压紧量、差速控制验证

---

## 下一步给工程

@全栈工程师 请以 v1.2a 为新主线基准，不再沿 v1.2 长筒理解。

优先检查：
1. 短圆管长度 `76mm` 是否足够做几何导向
2. 三电机嵌入口袋是否互相干涉
3. 外转子旋转包络与 saddle / 管壁间隙
4. 45×45 单端固定与主框架接口
5. `+Z` 出口轴线与发射方向是否满足总装要求

---

## 结论
v1.2a 是主线收紧版：
- 短圆管 / 短环中心
- 三外转子嵌入夹持
- 以圆管出口为发射方向
- 保留 45×45 单端安装
- 为后续几何干涉、运动包络、50m/RPM、180° 弧线控制仿真做基准

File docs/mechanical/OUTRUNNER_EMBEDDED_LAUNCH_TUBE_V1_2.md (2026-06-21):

# OUTRUNNER_EMBEDDED_LAUNCH_TUBE_V1_2

## 本轮 owner 指令归纳

基于最新图片与文字，结构方向明确调整为：

1. **粉色圆环去掉**
   - 不再做独立外置环形支架视觉
   - 改为发射圆管本体承载结构

2. **3 外转子电机嵌入发射圆管**
   - 三个 6354 外转子直接嵌入管壁开窗/口袋
   - 外转子工作面伸入球道，与球直接接触
   - 保持三电机 120° 分布

3. **电机翻转 180°**
   - 相比 v1.1a，电机端面/固定端方向翻转
   - 让固定端、线束端、维护侧更接近参考图

4. **继续一端 4 螺丝 45×45 固定**
   - 保留单端主安装板
   - 四孔方阵 45×45
   - 默认 M5 间隙孔：`5.5mm`

5. **性能目标进入工程验证**
   - 距离目标：50m
   - 发射弧线：180° 可控
   - 这两项不能靠静态外形保证，必须进入 3D/动力学仿真与转速闭环验证

对应 CAD：
- `cad/assembly/p0-single-ball-launcher-v3/outrunner_embedded_launch_tube_v1_2.scad`

---

## v1.2 结构定义

### 1. 发射圆管作为主结构
v1.2 不再把中心环作为外观主体，而是采用：
- 短发射圆管
- 管壁三处嵌入式电机窗口
- 管体外侧一体加强肋
- 单端 45×45 主安装接口

### 2. 三外转子嵌入管壁
每个电机站位包括：
- 管壁窗口
- 嵌入式电机口袋
- 背部 saddle 支撑
- 单侧端面固定夹板
- 外转子壳体伸入球道 `2–3mm`

目标：
- 不做独立摩擦轮
- 不靠轴驱动球
- 直接用外转子壳体 / 包胶层接触球

### 3. 电机翻转 180°
CAD 中加入：
```scad
motor_flip_180 = true;
```
含义：
- 固定端/端夹方向按参考图翻转
- 后续如果工程端确认线束/端面方向相反，只改这个参数即可

### 4. 单端 45×45 固定接口
继续锁定：
```scad
main_mount_pitch  = 45;
main_mount_hole_d = 5.5;
```
主安装板仍是一端固定，便于接入总装外框。

---

## 保留参数口径

```scad
motor_d             = 63;
motor_len           = 54;
inner_d             = 232;
contact_sink        = 2.5;
contact_sink_min    = 2.0;
contact_sink_max    = 3.0;
rubber_sleeve_t     = 1.5;
main_mount_pitch    = 45;
```

---

## 性能目标拆解

### A. 距离加强到 50m
50m 不是外观参数，是系统性能目标，需要验证：

1. 外转子有效线速度
2. 球与外转子接触时间
3. 包胶摩擦系数
4. 压紧量 2–3mm 是否足够传递能量
5. 球体变形与能量损耗
6. 三电机转速同步误差
7. 出口角度与初速度

#### 初步工程判断
- 结构上必须预留更高转速与更高夹持刚性
- 包胶后动平衡必须前置验证
- 50m 目标不建议直接跳制造，应先做仿真 + 台架测速

### B. 发射弧线 180° 可控
“180° 可控”应拆成控制目标：

1. 水平/俯仰出射角可调
2. 三电机差速可控
3. 通过上下/左右转速差生成旋转与弧线
4. 出球角度、初速度、球旋转速度可测

#### 设计含义
- CAD 只表达结构空间
- 真正的 180° 弧线控制来自：
  - 三电机独立转速控制
  - 可调安装角/整体发射角
  - 控制算法与测速反馈

---

## 3D 仿真路线：由简入繁，多轮更新

### Step 1：几何干涉仿真
目标：确认能装进去。
- 三个 6354 与发射圆管是否干涉
- 管壁窗口是否覆盖外转子工作带
- 45×45 安装板与外框是否冲突
- 防护罩/线束/工具空间是否够

输出：
- 干涉截图
- 最小间隙表
- v1.2a 修改清单

### Step 2：运动包络仿真
目标：确认转得起来。
- 外转子旋转包络
- 包胶后最大外径
- 防护罩安全间隙
- 球通过时的最小通道

输出：
- 旋转包络图
- 球路剖面图
- 风险点标注

### Step 3：简化动力学仿真
目标：估算 50m 所需初速度与转速区间。
- 球质量
- 出射角
- 空气阻力简化
- 目标距离 50m
- 初速反推

输出：
- 初速度范围
- 电机表面线速度范围
- 推荐 RPM 区间

### Step 4：接触/摩擦仿真
目标：验证能量能不能传给球。
- 包胶摩擦系数
- 压紧量 2/2.5/3mm 扫描
- 接触时间
- 球体变形
- 三轮同步误差

输出：
- 压紧量推荐值
- 包胶厚度建议
- 是否需要提高筒长/接触弧长

### Step 5：弧线控制仿真
目标：验证 180° 可控范围。
- 三电机差速模型
- 出球自旋方向
- 左右/上下弧线趋势
- 控制查表

输出：
- 电机转速组合表
- 预期轨迹族
- 控制边界

---

## 当前 v1.2 风险

### 1. 嵌入管壁后散热更差
电机被管壁包围后：
- 热堆积更明显
- 需要开散热槽或导风罩
- 防护罩不能完全封死

### 2. 50m 目标可能要求高转速
高转速带来：
- 包胶动平衡风险
- 轴承负载上升
- 外转子壳体安全风险

### 3. 2–3mm 压紧量可能不足或过大
要靠实测判断：
- 不足：打滑，距离不够
- 过大：球损伤、电机负载过高、堵球

### 4. 180° 弧线控制不是纯结构问题
需要电控与传感配合：
- 三电机独立闭环
- 出球测速
- 转速差控制
- 发射角机械调节

---

## 下一步建议

1. @全栈工程师 接 v1.2 做几何干涉与主线并线
2. 建立 `ENGINEERING_SIMULATION_PLAN_V1_2.md`
3. 先做 Step 1 / Step 2：几何与运动包络
4. 50m 与 180° 弧线进入 Step 3–5，不直接承诺制造
5. 我这边根据干涉反馈出 `v1.2a`

---

## 设计结论
v1.2 已按最新图纠偏：
- 去掉独立粉色圆环
- 三电机嵌入发射圆管
- 电机翻转 180°
- 保留一端 45×45 四螺丝固定
- 把 50m 与 180° 弧线从外观需求拆成工程验证目标

这版应作为下一轮 3D 仿真与工程验证起点。

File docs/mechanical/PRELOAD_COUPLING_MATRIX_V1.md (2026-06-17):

# PRELOAD_COUPLING_MATRIX_V1

## 目的
把 `包胶厚度` 与 `压紧量` 的联动从口头判断改成显式表格，避免 `v1.2` 阶段在未校核情况下锁死错误组合。

当前冻结参数：
- `inner_d = 232`
- `motor_d = 63`
- `contact_sink = 2.0 ~ 3.0 mm`
- 默认 `contact_sink = 2.5 mm`
- `rubber_sleeve_t = 1.5 mm`（当前 CAD 名义值）

---

## 一阶估算口径
在当前 CAD 表达里，可先按下面的一阶估算判断风险：

```text
理论有效压紧 ≈ contact_sink + rubber_sleeve_t
```

说明：
- `contact_sink` 表达的是电机工作带向球道侵入的基准量
- 若外转子外表面再包一层胶，接触外径会继续增大
- 真实压紧量仍要靠实物装配复核，这里只是 v1.2 阶段的先行筛选表

---

## 联动矩阵（单位：mm）

| `rubber_sleeve_t` \ `contact_sink` | 2.0 | 2.5 | 3.0 |
|---|---:|---:|---:|
| 0.0 | 2.0 | 2.5 | 3.0 |
| 1.0 | 3.0 | 3.5 | 4.0 |
| 1.5 | 3.5 | 4.0 | 4.5 |
| 2.0 | 4.0 | 4.5 | 5.0 |

---

## 当前工程判断
### 可直接落在目标区间 `2–3mm` 的组合
只有这些组合一阶上是安全的：
- `rubber_sleeve_t = 0.0` + `contact_sink = 2.0 / 2.5 / 3.0`
- `rubber_sleeve_t = 1.0` + `contact_sink = 2.0`（临界上限）

### 当前名义值的风险
若保持：
- `contact_sink = 2.5`
- `rubber_sleeve_t = 1.5`

则一阶估算：
```text
理论有效压紧 ≈ 4.0 mm
```

这已经明显高于当前 `2–3mm` 目标区间。

---

## v1.2 阶段建议
### 优先验证顺序
1. 先确认是否真的需要连续包胶
2. 若需要，先压缩包胶厚度候选值
3. 再看是否要把默认 `contact_sink` 下调
4. 最后再决定是否需要改局部调节范围

### 当前建议口径
在实测之前，不建议同时默认：
- `rubber_sleeve_t = 1.5`
- `contact_sink = 2.5`

更稳妥的验证起点：
- 方案 A：`rubber_sleeve_t = 0 ~ 0.5`，`contact_sink = 2.5`
- 方案 B：`rubber_sleeve_t = 1.0`，`contact_sink = 2.0`

---

## 通过标准
满足以下全部条件，才算这一项通过：
1. 实测装配后的有效压紧量可稳定落在 `2–3mm`
2. 调节只需短行程微调，不引入新结构方向
3. 球表面不会因过压而显著受损
4. 电机负载和振动不会因过压异常上升

---

## 失败后的修改路径
### 情况 1：压紧量 > 3mm
优先级：
1. 降低包胶厚度
2. 下调 `contact_sink`
3. 必要时修正局部调节槽表达
4. 若仍超限，再进入 `v1.1a`

### 情况 2：压紧量 < 2mm
优先级：
1. 增加包胶厚度
2. 上调 `contact_sink`
3. 用短槽/垫片微调

---

## 结论
这张表的作用不是替代实测，而是先把高风险组合排掉。

按当前 CAD 名义值看，**包胶厚度是 v1.2 最先需要收口的变量之一**，否则很容易把压紧量直接推离目标区间。

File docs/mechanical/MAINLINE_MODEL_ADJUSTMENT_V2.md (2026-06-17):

# MAINLINE_MODEL_ADJUSTMENT_V2

## 目标
把当前 6354 主线模型从“几何占位”推进到“工程并线可评审”状态，并吸收 `outrunner_launch_tube_v1_1` 的接口信息。

当前并线基准：
- 主线模型：`cad/assembly/p0-single-ball-launcher-v2/p0_single_ball_launcher_outer_rotor_parametric_v10.scad`
- 发射筒版本：`cad/assembly/p0-single-ball-launcher-v3/outrunner_launch_tube_v1_1.scad`

---

## 并线检查结论

### 1. 几何主线一致，可并线
两边当前几何口径一致：
- 6354 外转子
- 三电机中心线同平面
- 三工位等边三角形 / 120° 均布
- 3 外转子与球直接接触
- 底面固定逻辑成立
- 可调，但刚性优先

### 2. 需要显式对齐的参数
当前应统一按下列参数做工程评审：

| 参数 | 主线当前 | v1.1 当前 | 结论 |
|---|---:|---:|---|
| `ball_d` | 220 | 220 | 一致 |
| `motor_d` | 63 | 63 | 一致 |
| `motor_len` | 53.5 / 6354 占位 | 54 | 统一按 54 占位 |
| `inner_d` | `ball_d + ring_clearance = 236` | 232 | **优先按 232 收口** |
| `preload/contact_sink` | preload = 4 | 2–3，默认 2.5 | **主线需改为 2.5 默认，2–3 可调** |
| 固定方式 | bottom-face mount | end-face bridge + base-side adjust expression | 需保留“底面固定优先”口径，同时把近底座微调表达补进主线 |

### 3. 当前关键差异
主线 v10 仍偏“总装关系表达”，不足以覆盖 v1.1 的以下信息：
- `inner_d=232` 的发射筒边界
- 2–3mm 压紧量的可调区间
- 端面槽孔化安装孔位表达
- 三侧透明防护罩安装孔位
- 开窗圆角 / 内侧 relief
- 近固定端的小行程调节结构表达

因此当前建议不是简单替换，而是：
**v1.1 作为发射筒与电机接口子模型基线，主线总装继续保留 v10，但参数与接口说明必须同步。**

---

## 主线模型调整动作

### A. 立即同步的参数
建议主线模型下一版至少同步：

```scad
motor_series = "6354";
motor_body_d = 63;
motor_body_len = 54;      // 不再用 53.5 占位
ring_clearance = 12;      // 对齐 inner_d = 232
preload = 2.5;            // 作为默认压紧量
```

并在注释中明确：
- 压紧量允许 2–3mm 调整
- 包胶厚度变化会直接改变最终压紧量
- 实测电机尺寸未锁前，孔距仍为参数占位

### B. 支撑路径强化
主线当前已有：
- 电机底面支撑座
- 双立柱
- 斜撑
- 三工位对称支撑

下一版建议继续强化：
- `mount_base_t`：继续加厚，优先表达底部支撑座刚性
- `brace_t`：增加到更明显的工程表达级别
- 缩短 `brace_len`，让支撑链路更短
- 三工位保持完全同构，不允许一侧先特殊化

### C. 调节结构并线
把 v1.1 的“近固定端小行程调节”吸收到主线：
- 只允许近底座 / 近固定端做短槽调节
- 不允许在环边缘长悬臂调节
- 不允许调节件成为主承载件

推荐表达：
- 底座短槽 + 定位孔
- 垫片 / 分级孔位
- 螺栓组驱动的短行程微调

### D. 接口件信息补充
主线文档需要补充以下接口状态：
- 端面孔距未锁，保持参数化槽孔
- 包胶厚度未锁，需与压紧量联动校核
- 包胶后动平衡为单独验证项
- 透明防护罩需复核散热与装配空间

---

## 对设计师的接口反馈（v1.1a 仅在需要时修改）
当前先不要求大改，v1.1 可以保持冻结。

仅保留以下潜在 `v1.1a` 触发条件：

1. **主线确认继续使用 `inner_d=232`** 后，如发现：
   - 球道与窗口边界距离不足
   - 防护罩孔位与外框干涉
   - 包胶后压紧超过 3mm
   再做定点修正。

2. **6354 实测孔位出来后**，若与当前默认槽孔偏差过大：
   - 调整 `mount_hole_x_spacing`
   - 调整 `mount_hole_z_spacing`
   - 调整 `mount_slot_extra`

3. **防护罩与散热/维护冲突** 时：
   - 仅修正耳位位置或孔距
   - 不改变三窗口主几何

---

## 风险复核

### 必列验证项
1. 6354 实测外径 / 长度 / 端面孔距
2. 包胶厚度对压紧量的联动影响
3. 包胶后动平衡
4. 透明防护罩的散热 / 装配 / 维护空间
5. 端面固定板与主线外框的工具进入空间

### 当前阶段判断
- **几何正确**：可以
- **固定逻辑正确**：可以
- **可调逻辑正确**：可以，但必须限制在小行程
- **可直接进制造**：还不行
- **可进入 v1.2 工程验证版**：**可以，前提是把上面 5 个验证项显式带上**

---

## 结论
当前建议：

1. **接受设计师 v1.1 作为发射筒子模型冻结版**
2. **主线总装按 232 内径 / 54 长度 / 2.5mm 默认压紧量同步参数**
3. **保留参数化槽孔，不写死 6354 端面孔距**
4. **列清楚包胶、动平衡、防护罩三类风险**
5. 满足以上条件后，**可进入 `v1.2 工程验证版`**

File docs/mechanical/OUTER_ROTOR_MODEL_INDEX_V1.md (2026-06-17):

# Outer Rotor Model Index v1

## Mainline file

Use this file first when reviewing the current preferred launcher-head concept:

- `cad/assembly/p0-single-ball-launcher-v3/outrunner_launch_tube_v1.scad`
- `cad/assembly/p0-single-ball-launcher-v3/outrunner_launch_tube_v1_1.scad`

`outrunner_launch_tube_v1.scad` remains the first baseline. `outrunner_launch_tube_v1_1.scad` is the current 6354 refinement with parameterized end-face slots, 2–3mm preload expression, shield tabs, and rib updates.

## Current design note

- `docs/mechanical/OUTRUNNER_LAUNCH_TUBE_V1.md`
- `docs/mechanical/OUTRUNNER_LAUNCH_TUBE_V1_1.md`
- `docs/renders/OUTRUNNER_LAUNCH_TUBE_THREE_VIEW_V1.svg`
- `docs/renders/OUTRUNNER_LAUNCH_TUBE_THREE_VIEW_V1_1.svg`

## Supporting files

### Ring-focused review
- `cad/assembly/p0-single-ball-launcher-v2/p0_single_ball_launcher_ring_focus_v2.scad`

### Motor placeholder
- `cad/vendor-placeholders/63xx-motor-v2/63xx_outer_rotor_bottom_mount_placeholder_v2.scad`

### Previous mainline / comparison
- `cad/assembly/p0-single-ball-launcher-v2/p0_single_ball_launcher_outer_rotor_mainline_v3.scad`

## Historical / comparison parametric files

These remain useful for review history and comparison, but they are not the first file to open now:

- `..._parametric_v3.scad`
- `..._parametric_v4.scad`
- `..._parametric_v5.scad`
- `..._parametric_v6.scad`
- `..._parametric_v7.scad`
- `..._parametric_v8.scad`

## Guidance

For current discussion, screenshots, and further iteration, prefer the `mainline` file unless a comparison turn explicitly needs one of the older parametric revisions.

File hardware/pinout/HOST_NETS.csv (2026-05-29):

Net | Category | Description
VIN_24V | power | 24V main input
+5V | power | 5V system rail
+3V3 | power | 3.3V logic rail
CAN_H | comm | CAN high
CAN_L | comm | CAN low
SIG_TUBE | sensor | tube ball sensor signal
SIG_CHAMBER | sensor | chamber ball sensor signal
SIG_EXIT | sensor | exit sensor signal
SIG_ESTOP | safety | estop feedback input
PWM_FEED | actuator | feed servo pwm
SOLENOID_LOW | actuator | solenoid low side drive
UART0_TX | debug | uart tx
UART0_RX | debug | uart rx

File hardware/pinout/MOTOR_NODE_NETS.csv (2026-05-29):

Net | Category | Description
VIN_24V | power | 24V node input
VDRV | power | gate driver supply
+3V3 | power | logic supply
PHASE_U | motor | motor phase U
PHASE_V | motor | motor phase V
PHASE_W | motor | motor phase W
HALL_A | sensor | hall channel A
HALL_B | sensor | hall channel B
HALL_C | sensor | hall channel C
ISENSE_A | analog | current sense A
ISENSE_B | analog | current sense B
VBUS_SENSE | analog | bus voltage sense
DRV_EN | control | driver enable
DRV_FAULT_N | control | driver fault
CAN_H | comm | CAN high
CAN_L | comm | CAN low

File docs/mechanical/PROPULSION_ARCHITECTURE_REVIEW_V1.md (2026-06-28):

# 推进架构评审 V1

> 状态：进行中
> 作者：全栈工程师
> 触发：纠偏主线（v1-v14 外观版本堆叠后未锁定推进机理）
> 关联：M0（电控）、M1（机械）、P0（球发射 P0 范围）

---

## 0. 背景与触发

v1-v14 的多版外观迭代暴露一个事实：

> **单靠"三电机径向相切"模型，不能可靠把球沿圆管推出。**

不论把电机轴设为：
- 平行于管（v1-v5、v11-v13）→ 接触点切向速度无 Z 分量 → 球绕管自旋
- 径向垂直于管（v6-v10、v14 飞轮盘）→ Z 分量存在但**沿管切向相互抵消**

如果继续在外观层面迭代，无法锁定发射机理，因此停止 v15+ 外观，先做这份架构评审。

---

## 1. 球被推出圆管的必要条件

球（标准 5 号，220 mm，~430 g）受合力 F_net。沿管轴（Z 向）发射要求：

```
F_net_z > 0   且   F_net_z 持续时间足够（球加速到目标速度）
```

三种力源分别贡献：

| 力源 | 提供 F_z | 物理本质 |
|---|---|---|
| 气压差 | **强** | ΔP × A_ball |
| 摩擦轮切向 | 弱且易抵消 | μ × N × cos(切向) |
| 球自旋 Magnus | 0 沿轴 | 只影响横向飞行 |

**关键判定**：仅靠摩擦轮的"切向速度分量投影到 Z"在 120° 对称下平均为 0（除非破坏对称性或角度倾斜）。

---

## 2. 三个候选方案

### 方案 1：纯三外转子摩擦推进

**结构**：3×6374 电机径向相切，圆筒形 cradle，钢/橡胶 can 包覆电机外转子，球夹在三 can 之间。

**力学分析**：
- 接触点切向速度方向：v_t = ω_can × R_can
- Z 分量：v_z = v_t × sin(θ_contact)
- 120° 对称 + 同向旋转 → **Z 分量总和 = 0**
- 球只绕管自旋，不前进

**实测/仿真（参考 sim/football_launch_model.py 拓展）**：
- 球线速度 v_ball ≈ 0（仅自旋 ω_spin 可达数千 RPM）
- F_z 净力 ≈ 0
- **判定：球不能沿管发射**

**适用场景**：
- 球定位（预转 / 姿态稳定）
- 球旋转控制（弧线 / 香蕉球）
- **不能**作为唯一轴向推进来源

**复杂度**：高（3 电机 + 3 闭环 + 差速同步）
**风险**：烧电机、过流堵转
**验证路径**：仅做控旋测试

---

### 方案 2：压缩空气主推进 + 三电机控旋（推荐主线）

**结构**：
- 圆管后端封闭（压力端），接储气罐 + 快释放阀
- 球装载在管中预定位置（球挡或传感器触发）
- 触发：电磁阀瞬时开启 → 高压气体推动球 → 球被推出
- 三电机（径向相切）只负责：
  - 出膛前球姿态调整（预转 / 对中）
  - 出膛瞬间施加旋转（弧线球）
  - 修正出球稳定性

**力学分析**：
- 气压推力 F_air = (P_tank - P_atm) × A_ball
- 假设 P_tank = 8 bar (gauge) = 9 bar absolute
  - A_ball = π × (110)² = 38013 mm² ≈ 0.038 m²
  - F_air ≈ 8 × 10⁵ × 0.038 ≈ 30 kN（理论峰值）
  - 实际有效力受阀门流量、压力衰减影响，约 2-5 kN 持续 50-100 ms
- 球加速：a = F/m ≈ 5000 / 0.43 ≈ 12000 m/s²（瞬时）
- 球出膛速度 v_exit ≈ sqrt(2 × ΔP × A_ball × L_press / m) ≈ 15-25 m/s（典型 50 m 射程）

**判定**：球可沿管高速发射，方向、速度可控

**优势**：
- 球速度仅由 ΔP 控制，调节简单
- 三电机解脱为"控旋模块"，可独立设计验证
- 机械复杂度大幅降低
- 已有商业足球发射器采用此原理（FORZA、Net World Sports）

**风险**：
- 压力容器安全（PLA 长时间承压会疲劳 → 必须用 ABS/CF-PETG/铝合金）
- 必须有爆破片 + 泄压阀 + 急停
- 高压气管接口、电控阀同步

**复杂度**：中等（气路 + 阀 + 简单电控）
**验证路径**：
1. 5 bar 低压空气炮原理验证（PVC 管 + 球 + 阀门）
2. 测出膛速度 vs 压力曲线
3. 加入三电机预转测试
4. 加弧线球测试

---

### 方案 3：斜置 / 螺旋接触轮提供轴向分力

**结构**：电机径向**倾斜 5-15°** 于管轴（不严格垂直），或 can 表面刻螺旋槽（螺纹）。

**力学分析**：
- 接触点速度方向 v_t 不在径向平面内
- v_t 与管轴有夹角 → Z 分量 v_z ≠ 0
- 例如：can 倾斜 10°，v_z ≈ v_t × sin(10°) ≈ 0.17 × v_t
- 球速度较方案 1 大幅提升

**判定**：可发射，但倾斜机构复杂

**优势**：
- 仍是纯电机方案，无气压安全风险
- 单电机也能产生轴向分力（类比斜传送带）

**劣势**：
- 倾斜导致机械磨损不对称
- 球旋转控制变难（侧向分力耦合）
- 不适合 50 m 远射程（速度上限受摩擦功率限制）

**复杂度**：中（机械倾斜机构 + 螺旋 can 加工）
**验证路径**：单轮倾斜 10° 测试出膛速度

---

## 3. 三方案对比矩阵

| 维度 | 方案 1<br>纯摩擦 | 方案 2<br>气压+电机 | 方案 3<br>斜置/螺旋 |
|---|---|---|---|
| 球能沿管发射 | ❌ 不能 | ✅ 能 | ✅ 能 |
| 仅原地打转 | ✅ 是 | ❌ 否 | ❌ 否 |
| 适合 50 m 目标 | ❌ 否（速度 0） | ✅ 是 | ⚠ 受限 |
| 出膛速度调节 | 仅靠 RPM | **直接 ΔP** | 倾斜角 + RPM |
| 旋转控制 | 强（同向/差速） | 中（短时施加） | 弱（耦合） |
| 机械复杂度 | 高 | 中 | 中 |
| 安全风险 | 低 | **高（压力容器）** | 低 |
| 验证周期 | 短 | 中（需气源） | 中 |
| **推荐度** | 否定（仅作控旋） | **主线推荐** | 备选 |

---

## 4. 主线结论

### 4.1 球发射的力源分工（推荐方案 2）

| 力源 | 角色 | 量化目标 |
|---|---|---|
| 压缩空气 ΔP | **主轴向推进** | 出膛 15-25 m/s，射程 30-50 m |
| 三电机径向 can | **控旋模块** | 自旋 0-2000 RPM 可调，弧线 ±5° |
| 重力 + 空气阻力 | 飞行段（不在本评审范围） | — |

### 4.2 三电机重新定位（不再做主推进）

电机的唯一职责：
- 球装载后、出膛前，对球预转
- 出膛瞬间可施加横向分力（弧线）
- 训练模式可纯电机低气压预转（无气）
- 故障保护（堵转 → 立即停气）

### 4.3 安全边界（气压方案必做项）

| 项目 | 要求 |
|---|---|
| 工作压力 | P0 ≤ 8 bar（gauge） |
| 爆破片 | 1.2× 工作压力标定 |
| 泄压阀 | 1.1× 工作压力开启 |
| 急停按钮 | 硬件 + 软件双切断 |
| 球装载互锁 | 球未到位禁止加压 |
| 发射方向 | 仅允许开阔室外、无人区 |
| 操作员距离 | ≥ 3 m |
| 屏蔽 | 球道 + 操作员之间物理隔板 |

### 4.4 验证路径（4 阶段）

**Stage 1：纯气炮原理验证（无电机）**
- 5 bar PVC 管 + 球 + 手动球阀
- 测出膛速度 vs ΔP 曲线
- 验证球确实沿管发射、速度可调
- **预计 1 周**

**Stage 2：加电磁阀 + 简单电控**
- 12V 电磁阀 + 按钮触发
- 加压力传感器 + 泄压
- 测重复性、一致性
- **预计 1-2 周**

**Stage 3：加三电机控旋模块**
- 现有 v9/v14 电机模块接入（径向）
- 测预转 → 触发 → 出膛的时序
- 测弧线球（差速预转 → 侧偏）
- **预计 2 周**

**Stage 4：整合 + 50 m 实地测试**
- 全部集成：气路 + 电控 + 三电机
- 安全联锁全开
- 50 m 射程标定
- **预计 2 周**

---

## 5. 仿真口径更新建议

需要更新 `sim/football_launch_model.py`：

### 新增"轴向推进来源"层

```python
# sim/football_launch_model.py 扩展

PROPULSION_SOURCES = {
    'friction_3rotor': {  # 方案 1
        'F_z_net': 0,           # Z 分量净力 = 0
        'ball_velocity': 0,     # 仅自旋
        'rotation': 'high',
    },
    'pneumatic_primary': {  # 方案 2
        'F_z_net': 'pressure_driven',
        'pressure_range_bar': (2, 8),
        'ball_velocity_range': (5, 25),  # m/s
        'rotation': 'motor_controlled',
    },
    'tilted_rotor': {       # 方案 3
        'F_z_net': 'tilt_angle_dependent',
        'tilt_range_deg': (5, 15),
        'ball_velocity_range': (3, 12),
        'rotation': 'partial_control',
    },
}
```

### 区分力源

| 力 | 公式 | 来源 |
|---|---|---|
| F_air | (P - P_atm) × A_ball | 气压 |
| F_friction_z | μ × N × cos(θ_contact) × sin(φ_tilt) | 摩擦轮（含倾斜补偿） |
| F_magnus | ρ × v × Γ × L | 球自旋（仅横向） |

### 输出字段

```
v_exit_z, v_exit_xy, ω_spin, ΔP, tilt_angle, F_z_net
```

---

## 6. 拒绝 v15 外观迭代的原因

1. v11-v14 全部基于错误的轴向力假设
2. 继续迭代外观只会累积错误先例
3. 必须先锁机理，再做 CAD
4. **不锁定本评审（特别是否定方案 1 作为主推进），不允许任何 v15+ 外观工作**

---

## 7. 设计师协同项（@设计师）

设计师接到的任务（不在本评审范围，但需要在评审通过后执行）：
- 中央圆管压力端结构草图（含密封、法兰）
- 压缩空气接口占位（不实际做气路）
- 三电机控旋模块布局（独立组件，不挡主发射通道）
- 球通过路径剖面图
- 哪些必须拆分打印（高压端 vs 低压端 vs 维护件）

---

## 8. 待确认项

| 项目 | 默认假设 | 需 PM 确认 |
|---|---|---|
| 工作压力 | ≤ 8 bar | 是否调整 |
| 压力源 | 外部压缩机 | 气瓶 / 手泵 / 车载？ |
| 出膛速度 | 15-25 m/s | 目标射程 → 反推速度 |
| 球旋转 | 0-2000 RPM | 弧线幅度 ±5° 可调？ |
| 控旋强度 | 出膛瞬间施加 | 预转 vs 出膛同时？ |
| 训练场 | 室外 50 m | 长度、地面材质？ |

---

## 9. 评审完成判据

- [x] 三方案对比完成
- [x] 球是否能沿管发射判定
- [x] 三电机角色重新定位
- [x] 压缩空气是否进入主线判定
- [ ] PM 收口确认
- [ ] 仿真口径更新（待批准后）
- [ ] 设计师结构概念修正启动（待批准后）

---

## 变更日志

- V1：初版，纠偏主线、否决方案 1 作为主推进、推荐方案 2 为主线

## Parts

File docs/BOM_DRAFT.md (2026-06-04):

# 最小硬件 / BOM 草案

> 目标：先完成 P0 验证，不追求量产 BOM。

## 1. 上位控制
- `ESP32-S3` 控制板 × 1
- 作用：参数下发、状态汇总、调试串口 / Wi-Fi

## 2. 电机控制节点
- P0-A 台架：`B-G431B-ESC1` × 3，仅用于低功率闭环验证 / 代码 bring-up
- P0-B 实机：SimpleFOC 兼容高电流三相驱动 × 3，DRV8353 / DRV8302 级或等效方案，持续电流按工程复核值选型
- 说明：B-G431B-ESC1 不能直接等同于 6374 实球发射的最终高功率驱动

## 4. 电机
- 带 Hall 的 `6374 BLDC` × 3
- 建议 KV：`170~190KV`
- 说明：P0 优先带 Hall，降低起步和测速调试成本

## 4. 速度 / 位置反馈
- Hall 反馈线束 × 3
- 增强备选：`AS5048A` × 3（非 P0 必需）

## 5. 供电
- `24V LiFePO4 40~60Ah` 电池包 × 1（P0 优先）
- BMS 持续电流建议 `>=150A`，峰值建议 `>=250A`
- 总保险：`150A`；每路支路保险：`40A ×3`
- 结构与动力侧预留 `36V` 升级位，用于后续更稳定覆盖 `18~22 m/s`
- 急停两级切断回路 × 1（先 EN，后主动力）

## 6. 输入 / 保护
- 物理急停按钮 × 1
- 发射位球检测传感器 × 1
- 出球检测传感器 × 1（可选，用于测速/日志）
- 电源总开关 × 1
- 保险丝 / 过流保护模块 × 1

## 7. 机械
- 摩擦轮 × 3（轮径按球径联动，P0 先做 `90~130mm` 可替换轮组）
- 电机安装支架 × 3
- 手动上球导向口 × 1
- 短导向筒 / 可拆导向段 × 1（只用于初始姿态稳定，不作为供球管道）
- 110/130mm 可替换摩擦轮组 × 1 套
- 检修开口 × 1
- 防护罩 × 1 套

## 8. 调试
- USB 调试线 × 1
- 示波器 / 逻辑分析仪（建议）
- 转速观测方案（串口 / 上位机）

## 待 owner / 工程确认
1. 电机 KV / 功率范围
2. 摩擦轮直径和材质
3. 目标球速和目标射程
4. 是否要在 P0 加入俯仰调角机构
5. 高电流驱动板最终型号 / 采购渠道

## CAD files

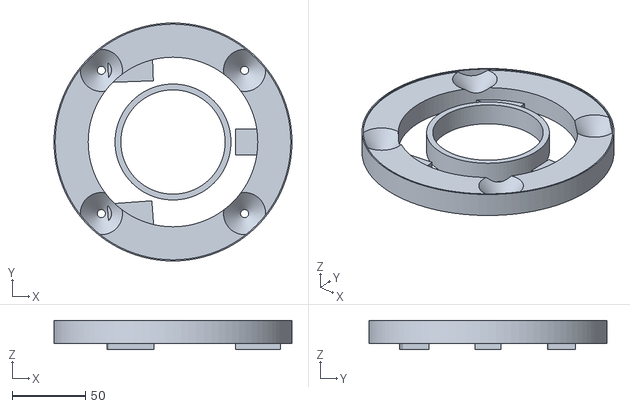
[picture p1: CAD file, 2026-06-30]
cad/3d-print/independent-wheels-v20/stls/cradle_wheel_v20.stl
162.1 x 162.1 x 19.8

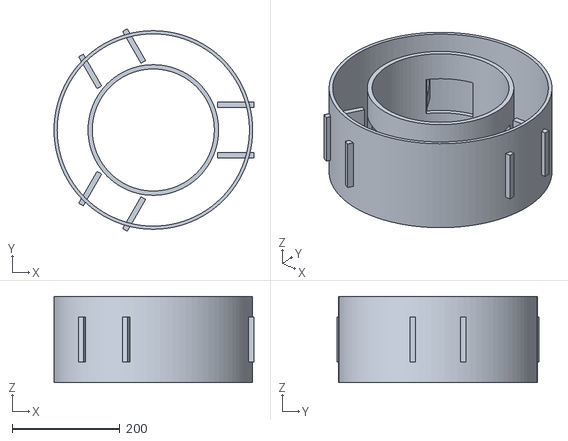
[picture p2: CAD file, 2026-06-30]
cad/3d-print/monocoque-tangent-v18/stls/monocoque_v18.stl
370.5 x 375.0 x 160.0

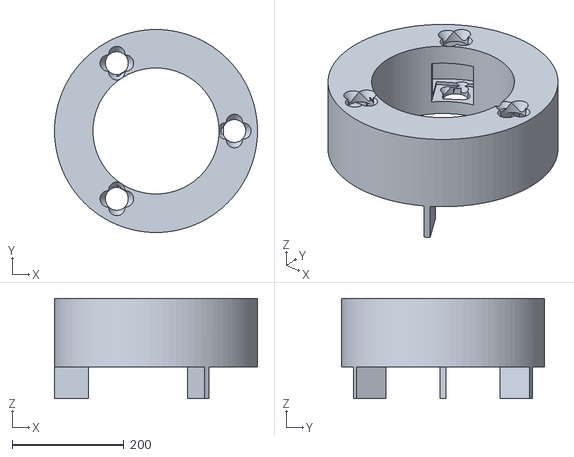
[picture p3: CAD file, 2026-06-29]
cad/3d-print/monocoque-v17/stls/monocoque_v17.stl
364.0 x 364.0 x 180.0

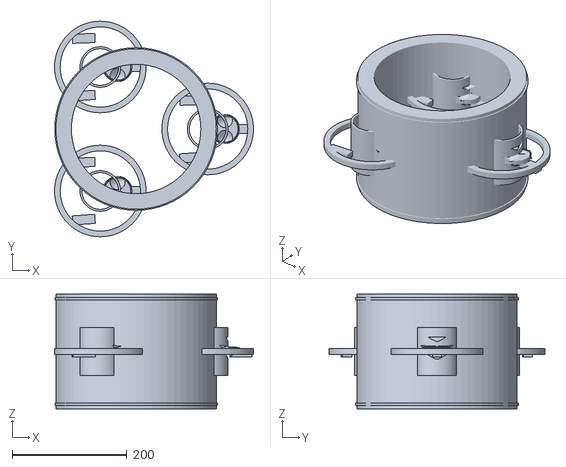
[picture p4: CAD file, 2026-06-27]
cad/3d-print/tri-motor-6374-v14/stls/spider_body_v14.stl
347.5 x 376.5 x 200.0

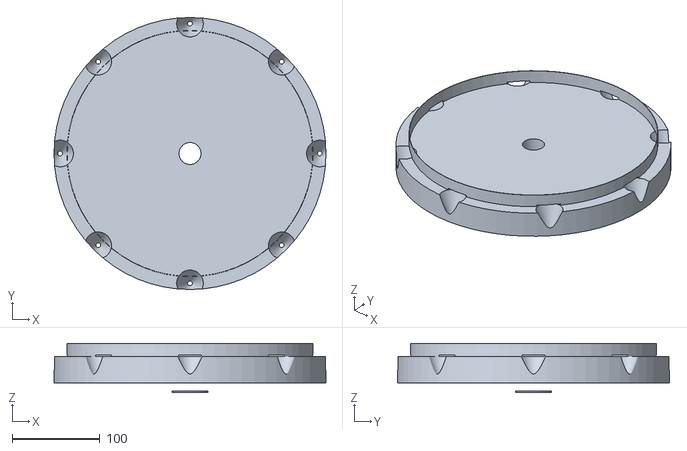
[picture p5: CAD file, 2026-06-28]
cad/3d-print/tri-motor-pneumatic-v15/stls/pressure_end_v15.stl
310.0 x 310.0 x 56.0

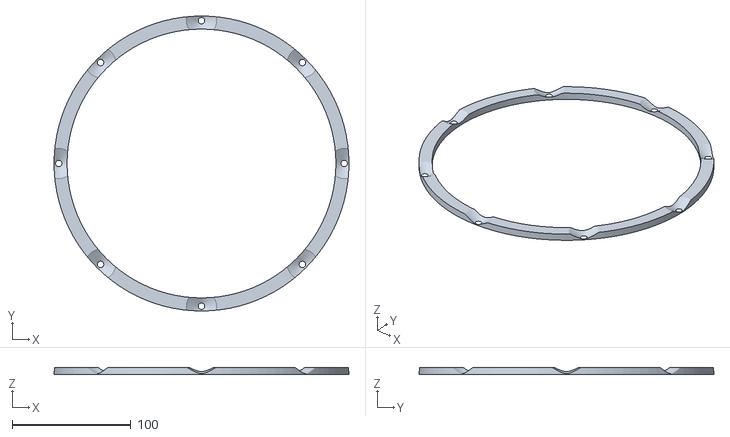
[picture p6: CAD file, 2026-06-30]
cad/3d-print/independent-wheels-v20/stls/side_plate_v20.stl
248.0 x 248.0 x 6.00

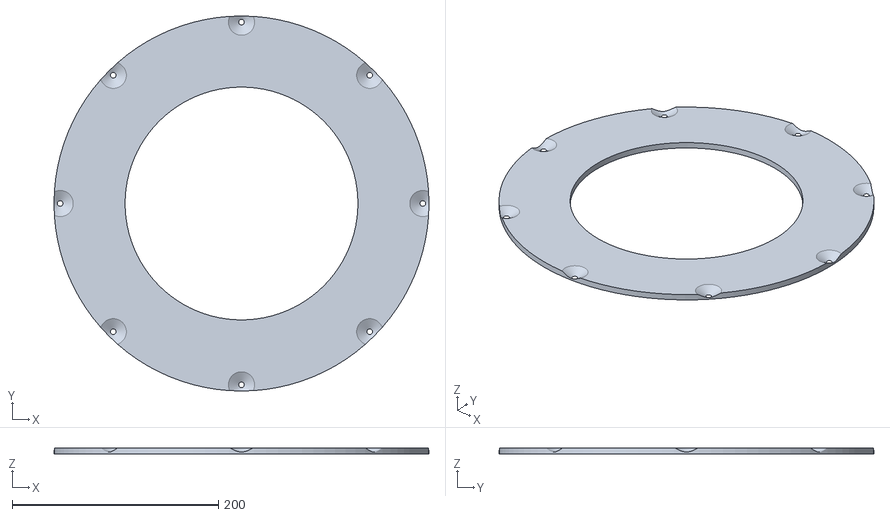
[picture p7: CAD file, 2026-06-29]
cad/3d-print/monocoque-v17/stls/side_plate_v17.stl
364.0 x 364.0 x 6.00

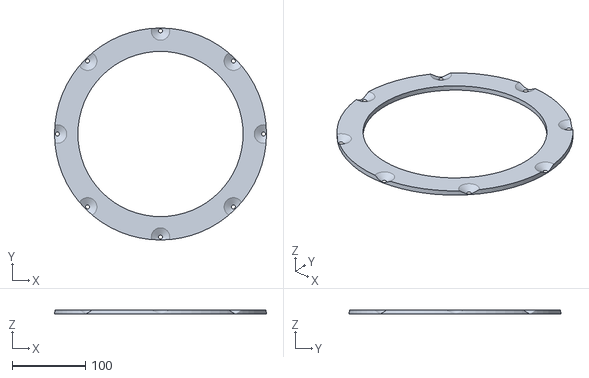
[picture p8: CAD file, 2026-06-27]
cad/3d-print/tri-motor-6374-v14/stls/side_plate_v14.stl
290.0 x 290.0 x 6.00

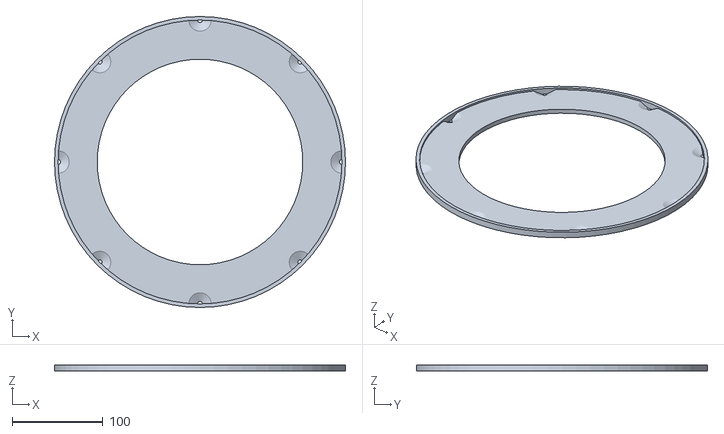
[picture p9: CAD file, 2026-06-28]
cad/3d-print/tri-motor-pneumatic-v15/stls/output_end_v15.stl
320.0 x 320.0 x 7.00

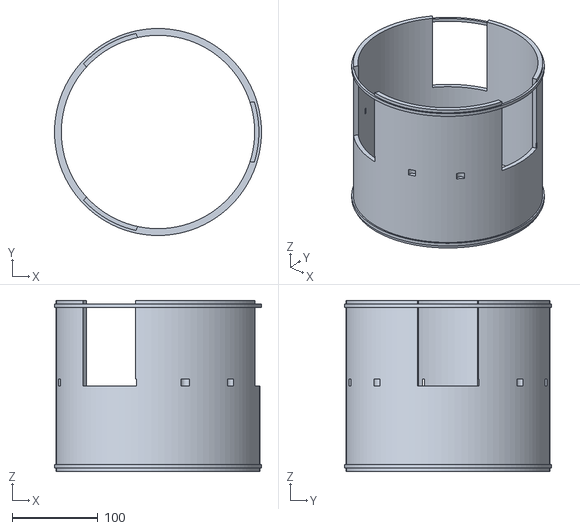
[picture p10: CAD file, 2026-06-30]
cad/3d-print/independent-wheels-v20/stls/tube_v20.stl
242.0 x 242.0 x 200.0

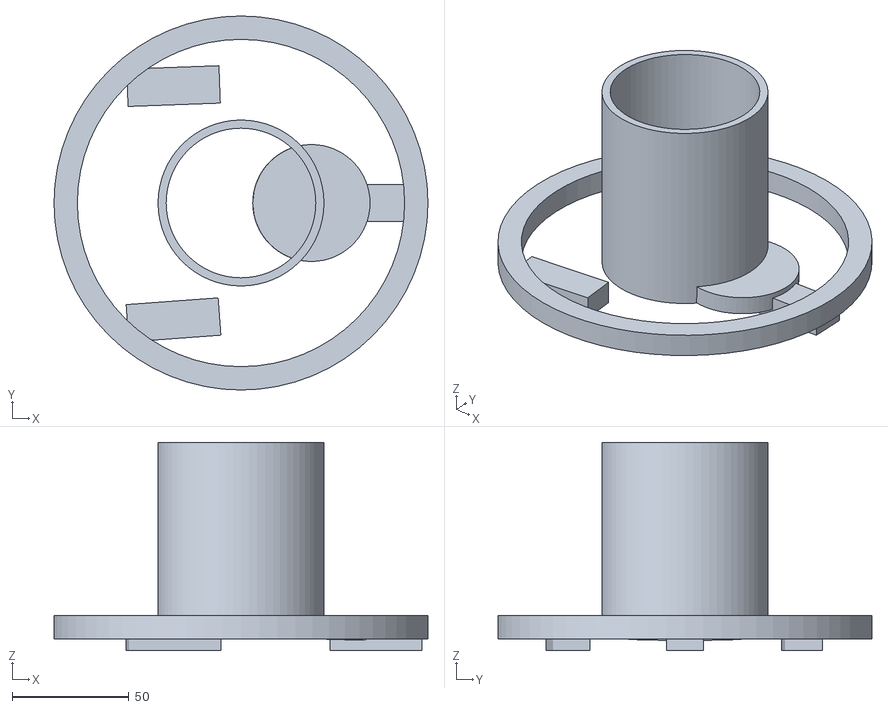
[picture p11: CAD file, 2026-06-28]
cad/3d-print/tri-motor-pneumatic-v15/stls/motor_cradle_v15.stl
160.0 x 160.0 x 89.0

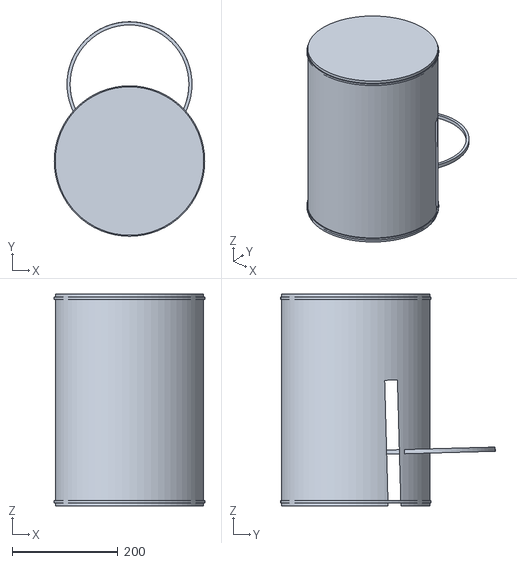
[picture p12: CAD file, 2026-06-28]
cad/3d-print/tri-motor-pneumatic-v15/stls/tube_body_v15.stl
284.0 x 405.0 x 400.0

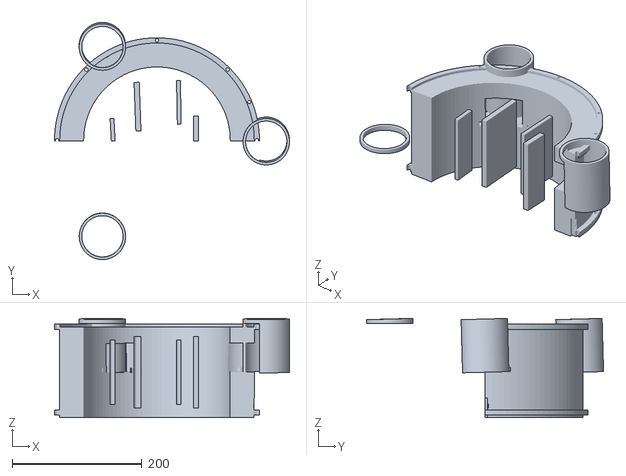
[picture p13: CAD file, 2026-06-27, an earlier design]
cad/3d-print/tri-motor-6374-v1/stls/monocoque_shell.stl
362.3 x 365.6 x 153.0

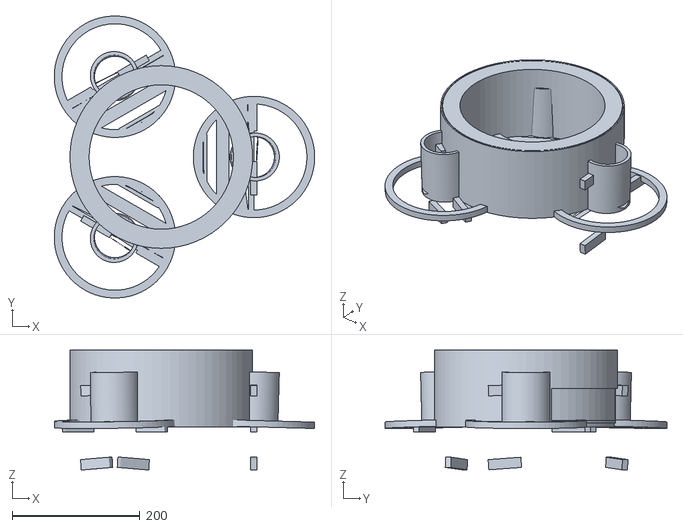
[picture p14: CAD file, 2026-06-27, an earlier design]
cad/3d-print/tri-motor-6374-v10/stls/spider_body_v10.stl
407.8 x 441.5 x 187.2

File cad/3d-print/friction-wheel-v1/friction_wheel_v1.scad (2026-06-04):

// Friction wheel placeholder v1
// Units: mm
// Supports 110mm / 130mm variants for P0-A/P0-B layout.

$fn = 128;
wheel_d = 110;       // set to 130 for P0-B candidate
wheel_w = 45;
bore_d = 8;
hub_d = 36;
hub_w = 18;

module friction_wheel(d=wheel_d, w=wheel_w) {
  difference() {
    union() {
      color("#111827") cylinder(h=w, d=d, center=true);
      color("#475569") cylinder(h=hub_w, d=hub_d, center=true);
    }
    cylinder(h=w+2, d=bore_d, center=true);
  }
}

friction_wheel();

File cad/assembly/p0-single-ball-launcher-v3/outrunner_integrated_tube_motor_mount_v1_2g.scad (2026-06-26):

// SimpleFOC football launcher - integrated launch tube + 3-motor mount monocoque layout v1.2g
// Tightened from v1.2 per PM/new reference image:
// - center is a SHORT tilted tube/ring, not a long launch barrel
// - 3 outrunners wrap around the tube and contact the ball near the tube wall
// - motors are embedded/clamped into the tube-side structure, not external bolt-on modules
// - integrated monocoque: launch tube, motor pockets, end plates and ribs are one orange structural body
// Units: mm

$fn = 128;

// ---------- Core parameters ----------
ball_d                    = 220;
ball_clearance            = 12;
inner_d                   = ball_d + ball_clearance;   // 232 baseline
inner_r                   = inner_d/2;

short_tube_len            = 76;     // key change: short guide tube / short ring, not a long barrel
short_tube_wall           = 9;
launch_tilt_deg           = 18;      // three embedded motors tilted for direct upward launch
station_roll_deg          = 90;      // roll/flip tilted three-motor station by 90deg
photo_ref_embedded        = true;    // motors are embedded into tube-side cradle, not external add-ons
target_resultant_locked   = true;    // initial resultant direction is target direction; diff RPM creates spin/curve only
integrated_monocoque      = true;    // v1.2g: tube and three motor mounts are one integrated structure
photo_like_orange_body    = true;    // photo-reference orange printed body
tube_outer_r              = inner_r + short_tube_wall;
front_lip_t               = 8;
rear_lip_t                = 8;
lip_extra_r               = 10;

// 6354 baseline
motor_d                   = 63;
motor_len                 = 54;
motor_flip_180            = true;
contact_sink              = 2.5;
contact_sink_min          = 2.0;
contact_sink_max          = 3.0;
contact_sink_safe         = min(max(contact_sink, contact_sink_min), contact_sink_max);
rubber_sleeve_t           = 1.5;
spin_clearance            = 3;

// Embedded motor pocket around short tube
motor_center_r            = inner_r + motor_d/2 - contact_sink_safe;
pocket_tangent_w          = motor_len + 26;   // wider photo-like motor pocket blended into tube
pocket_z_len              = motor_d + 24;    // taller pocket/end-plate envelope
pocket_radial_depth       = short_tube_wall + motor_d + 20;
pocket_corner_r           = 10;
inner_relief_t            = 5;

// Clamp / saddle
saddle_back_t             = 10;
saddle_side_t             = 7;
saddle_z_margin           = 9;
end_clamp_t               = 8;
end_clamp_margin          = 10;
end_clamp_center_hole_d   = 24;
end_hole_d                = 5.5;
end_hole_pitch            = 45;
end_slot_extra            = 4;

// One-end 45x45 mount, offset to rear side of tube
main_mount_pitch          = 45;
main_mount_hole_d         = 5.5;
main_mount_pad_w          = 86;
main_mount_pad_h          = 86;
main_mount_pad_t          = 10;
main_mount_y              = tube_outer_r + motor_d + 30;
main_mount_z              = -short_tube_len/2 - 18;
main_mount_center_hole_d  = 14;

// Reinforcement only; protective shield removed per owner v1.2b
rib_t                     = 10;
rib_w                     = 18;
rib_extra                 = 22;
shield_hole_d             = 4.5;
shield_tab_t              = 5;
shield_tab_w              = 14;
shield_tab_z_gap          = 42;
shield_tab_x_gap          = motor_len + 24;

// Display toggles
show_ball_path            = true;
show_motors               = true;
show_contact_patches      = true;
show_mount                = true;
show_shield_tabs          = false;  // v1.2b: remove protective shield tabs from main baseline
show_launch_axis          = true;   // visualizes tilted three-motor resultant launch vector

// ---------- Helpers ----------
module rounded_rect_2d(w, h, r=6) {
  rr = min(r, min(w,h)/2 - 0.01);
  hull() {
    translate([-w/2+rr, -h/2+rr]) circle(r=rr);
    translate([ w/2-rr, -h/2+rr]) circle(r=rr);
    translate([-w/2+rr,  h/2-rr]) circle(r=rr);
    translate([ w/2-rr,  h/2-rr]) circle(r=rr);
  }
}

module slot_2d(len, w) {
  hull() {
    translate([-len/2+w/2,0]) circle(d=w);
    translate([ len/2-w/2,0]) circle(d=w);
  }
}

module pocket_cut() {
  translate([0, tube_outer_r - pocket_radial_depth/2 + 3, 0])
    linear_extrude(height=pocket_radial_depth, center=true)
      rounded_rect_2d(pocket_tangent_w, pocket_z_len, pocket_corner_r);
}

module inner_relief_cut() {
  translate([0, inner_r + inner_relief_t/2, 0])
    rotate([90,0,0])
      linear_extrude(height=inner_relief_t+1, center=true)
        rounded_rect_2d(pocket_tangent_w - 8, pocket_z_len - 8, 5);
}


module integrated_motor_pocket_body() {
  // Photo-reference monocoque: orange body grows from the tube wall into three motor pockets.
  for (a=[-90,30,150]) rotate([0,0,a]) {
    hull() {
      translate([0, tube_outer_r + 4, 0])
        cube([pocket_tangent_w*0.72, 12, pocket_z_len*0.72], center=true);
      translate([0, motor_center_r + motor_d/2 + 8, 0])
        cube([pocket_tangent_w, 18, pocket_z_len], center=true);
    }

    // End pressure plates with four screw bosses, visually close to the photo.
    for (sx=[-1,1]) {
      translate([sx*(motor_len/2+end_clamp_t/2), motor_center_r + motor_d/2 + 9, 0])
        difference() {
          cube([end_clamp_t+4, 20, motor_d+24], center=true);
          for (zz=[-end_hole_pitch/2, end_hole_pitch/2])
            translate([0, 0, zz]) rotate([90,0,0]) cylinder(d=end_hole_d, h=24, center=true);
        }
    }

    // Triangular-looking ribs from tube to motor pocket.
    for (sx=[-1,1])
      translate([sx*(pocket_tangent_w/2 + rib_w/3), tube_outer_r + rib_t/2, 0])
        cube([rib_w, rib_t, pocket_z_len + 2*rib_extra], center=true);
  }
}

module short_tube_body() {
  difference() {
    union() {
      // short center tube / ring
      difference() {
        cylinder(h=short_tube_len, r=tube_outer_r, center=true);
        cylinder(h=short_tube_len+2, r=inner_r, center=true);
      }

      // inlet/outlet lips: launch axis is tube axis, outlet = +Z
      for (z=[-short_tube_len/2 + rear_lip_t/2, short_tube_len/2 - front_lip_t/2])
        difference() {
          translate([0,0,z]) cylinder(h=front_lip_t, r=tube_outer_r + lip_extra_r, center=true);
          translate([0,0,z]) cylinder(h=front_lip_t+2, r=inner_r, center=true);
        }

      if (integrated_monocoque) integrated_motor_pocket_body();

      // integrated reinforcements around the embedded pockets
      for (a=[-90,30,150]) rotate([0,0,a]) {
        for (z=[-pocket_z_len/2-rib_w/2, pocket_z_len/2+rib_w/2])
          translate([0, tube_outer_r + rib_t/2, z]) cube([pocket_tangent_w+2*rib_extra, rib_t, rib_w], center=true);
        for (x=[-pocket_tangent_w/2-rib_w/2, pocket_tangent_w/2+rib_w/2])
          translate([x, tube_outer_r + rib_t/2, 0]) cube([rib_w, rib_t, pocket_z_len+2*rib_extra], center=true);
      }
    }

    for (a=[-90,30,150]) rotate([0,0,a]) pocket_cut();
    for (a=[-90,30,150]) rotate([0,0,a]) inner_relief_cut();
  }
}

module motor_shell() {
  rotate([0,90,0]) cylinder(d=motor_d, h=motor_len, center=true);
}

module end_clamp(side=1) {
  fixed_side = motor_flip_180 ? -side : side;
  x = fixed_side * (motor_len/2 + end_clamp_t/2);
  difference() {
    translate([x, motor_center_r, 0]) cube([end_clamp_t, motor_d+2*end_clamp_margin, motor_d+2*end_clamp_margin], center=true);
    translate([x, motor_center_r, 0]) rotate([0,90,0]) cylinder(d=end_clamp_center_hole_d, h=end_clamp_t+2, center=true);
    for (yy=[-end_hole_pitch/2, end_hole_pitch/2])
      for (zz=[-end_hole_pitch/2, end_hole_pitch/2])
        translate([x, motor_center_r+yy, zz])
          rotate([0,90,0])
            linear_extrude(height=end_clamp_t+2, center=true)
              slot_2d(end_hole_d+end_slot_extra, end_hole_d);
  }
}

module embedded_saddle() {
  // saddle is nested into the tube-side structure; inner side remains open for rotor contact.
  translate([0, motor_center_r + motor_d/2 + spin_clearance + saddle_back_t/2, 0])
    cube([motor_len+2*end_clamp_t, saddle_back_t, motor_d+2*saddle_z_margin], center=true);
  for (sx=[-1,1])
    translate([sx*(motor_len/2+saddle_side_t/2), motor_center_r, 0])
      cube([saddle_side_t, motor_d+2*saddle_z_margin, motor_d+2*saddle_z_margin], center=true);
}

module one_motor_station() {
  color([1.0,0.62,0.08,1]) embedded_saddle();
  color([1.0,0.48,0.05,1]) end_clamp(1);

  if (show_motors)
    color([0.82,0.90,1.0,0.60]) translate([0,motor_center_r,0]) motor_shell();

  if (show_contact_patches)
    color([1.0,0.86,0.18,0.88]) translate([0, inner_r-contact_sink_safe/2, 0])
      cube([motor_len*0.82, contact_sink_safe, motor_d*0.64], center=true);
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

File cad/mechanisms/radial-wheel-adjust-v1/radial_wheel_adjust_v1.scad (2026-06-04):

// Radial wheel adjustment mechanism v1
// Units: mm
// Purpose: support 110/130mm wheel swap and 5~15mm ball preload tuning.

$fn = 64;

base_w = 220;
base_h = 80;
base_t = 8;
slide_w = 170;
slide_h = 52;
slide_t = 8;
slot_len = 70;
slot_w = 10;
lock_hole_d = 6;
scale_marks = true;

module slot(len=slot_len, w=slot_w, h=base_t+2){
  hull(){
    translate([-len/2+w/2,0,0]) cylinder(h=h,d=w,center=true);
    translate([ len/2-w/2,0,0]) cylinder(h=h,d=w,center=true);
  }
}

module radial_adjust_base(){
  color("#94a3b8") difference(){
    cube([base_w,base_t,base_h],center=true);
    // two long radial slots
    translate([0,0,22]) rotate([90,0,0]) slot();
    translate([0,0,-22]) rotate([90,0,0]) slot();
  }
}

module radial_adjust_slider(){
  color("#64748b") difference(){
    translate([0,-12,0]) cube([slide_w,slide_t,slide_h],center=true);
    // motor shaft center clearance
    translate([0,-12,0]) rotate([90,0,0]) cylinder(h=slide_t+2,d=24,center=true);
    // provisional 6374 mounting holes
    for(x=[-35,35]) for(z=[-35,35])
      translate([x,-12,z]) rotate([90,0,0]) cylinder(h=slide_t+2,d=5.5,center=true);
  }
}

module locking_bolts(){
  color("#111827") for(x=[-45,45]) for(z=[-22,22])
    translate([x,-22,z]) rotate([90,0,0]) cylinder(h=24,d=lock_hole_d,center=true);
}

module preload_scale(){
  if (scale_marks) color("#111827") {
    for(i=[-20:10:20]) translate([i, -18, 42]) cube([1.5,2,10],center=true);
    translate([-35,-18,55]) linear_extrude(height=1) text("-20", size=8, halign="center");
    translate([  0,-18,55]) linear_extrude(height=1) text("0", size=8, halign="center");
    translate([ 35,-18,55]) linear_extrude(height=1) text("+20", size=8, halign="center");
  }
}

module radial_wheel_adjust(){
  radial_adjust_base();
  radial_adjust_slider();
  locking_bolts();
  preload_scale();
}

radial_wheel_adjust();

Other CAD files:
cad/3d-print/tri-motor-6374-v11/stls/spider_body_v11.stl
cad/3d-print/tri-motor-6374-v12/stls/spider_body_v12.stl
cad/3d-print/tri-motor-6374-v13/stls/spider_body_v13.stl
cad/3d-print/tri-motor-6374-v2/stls/launch_tube.stl
cad/assembly/p0-single-ball-launcher-v3/outrunner_integrated_tube_motor_mount_v1_2h.scad
cad/3d-print/short-guide-tube-v1/short_guide_tube_v1.scad
cad/3d-print/tri-motor-6374-v10/stls/motor_can_v10.stl
cad/3d-print/tri-motor-6374-v11/stls/motor_can_v11.stl
cad/3d-print/tri-motor-6374-v13/stls/motor_can_v13.stl
cad/3d-print/tri-motor-6374-v2/stls/bridge_rib.stl
cad/3d-print/tri-motor-6374-v2/stls/motor_can.stl
cad/3d-print/tri-motor-6374-v2/stls/side_plate.stl
cad/3d-print/tri-motor-6374-v2/stls/stator_mount.stl
cad/3d-print/tri-motor-6374-v3/stls/bridge_rib.stl
cad/3d-print/tri-motor-6374-v3/stls/launch_tube.stl
cad/3d-print/tri-motor-6374-v3/stls/motor_cradle.stl
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

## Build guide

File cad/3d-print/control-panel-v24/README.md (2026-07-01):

# Control Panel V1 — 升级到 HIFI Spec

## v23 → v24 升级

按设计师 `DISPLAY_UI_HIFI_SPEC_V1` 重新校准：

### 颜色规范（§2）
- 背景主色 `#080B0F` / 面板 `#121821` / 高亮 `#1B2430`
- 文字 `#F4F7FA` / `#AAB4C0` / `#6F7A86`
- 状态色：`#21C55D` 绿 / `#FACC15` 黄 / `#EF4444` 红
- 轨迹色：`#38BDF8` 预测蓝 / `#FB923C` 实测橙

### 字号（1024×600）
- 页面标题 28px / 主状态 36-44px / 按钮 24px / 标签 18px

### 触控尺寸（§2）
- 主按钮 64px 高 / 普通按钮 52px / 急停 120×56
- 滑条 40px 高 / 拖拽点 32px 直径

### 布局栅格（§1）
- 顶部状态栏 56px
- 主内容区 472px
- 底部安全栏 72px（含 4 Tab）

### 组件规范（§4）
- 状态卡：左 6px 状态条（绿/黄/红/灰）
- 模式按钮：默认 / 选中（蓝）/ 待确认（黄）/ 禁用（灰）
- 滑条：待确认时变黄，超限时变红
- 急停栏：固定底部，永不覆盖
- 轨迹图例：4 种元素清晰区分
- 错误卡：黄色警告 / 红色全局 Banner

### 自动锁定规则（§7）
```javascript
if emergency_stop == true:
  safety_locked = true
if system_errors contains severity == critical:
  safety_locked = true
if pressure > max_pressure:
  safety_locked = true
if motor rpm drift exceeds threshold:
  launch_ready = false
```

## v24 改进

| 改进 | v23 → v24 |
|---|---|
| 配色 | 通用色 → HIFI 规范色 |
| 字号 | 通用 → 28/36/44 大字号 |
| 触控 | 32px → 64px 主按钮 |
| 栅格 | 自由 → 56/472/72 固定 |
| 状态卡 | 普通边框 → 6px 左侧状态条 |
| 滑条 | 静态 → 待确认变黄 |
| 顶部栏 | 简单 → 完整信息（模式/电量/温度/视觉）|
| 状态联动 | 简单 → 5 种状态独立检查 |
| 发射按钮 | 仅 lock 判断 | 5 条件联动（lock + 急停 + 待确认 + 参数 + 故障）|
| 错误处理 | 单错误 | 红色全局 Banner + 自动 disable |
| 急停确认 | 直接触发 | 模态确认 + 全屏红锁 |

## 文件

- `control_panel_v24.html` — 重新生成的主交付文件（46 KB）

## 字段对齐

完全沿用 `DISPLAY_UI_WIREFRAME_V1` + `CONTROL_SYSTEM_ARCHITECTURE_V1` 字段集：

```
mode, launch_ready, safety_locked, emergency_stop, param_pending_confirm
pressure, propulsion_type, valve_delay, piston_force
motor_a/b/c_rpm, motor_a/b/c_temp
camera_status, camera_fps, vision_confidence
predicted_landing_x/y, actual_landing_x/y, distance_error, lateral_error
battery_percent, battery_voltage, system_errors[]
```

## 打开

```bash
open cad/3d-print/control-panel-v24/control_panel_v24.html
```

## 验证 PM 4 项要求

| 要求 | 实现 |
|---|---|
| 急停锁定 | ✓ 模态确认 + 全屏红锁 + 所有页底部栏同步 |
| 参数待确认 | ✓ 滑条变黄 + Banner + 模式按钮变黄 |
| 预测 vs 实测偏差 | ✓ SVG 双色轨迹 + 距离/横向分别显示 + 偏差颜色编码 |
| 故障自动锁定 | ✓ 错误列表 + 发射按钮 disable + 诊断页红条 |

## 依赖

无（纯 HTML/CSS/JS）。

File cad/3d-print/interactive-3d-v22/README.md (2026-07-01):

# Interactive 3D Display — v22

## 用途

用 **Plotly** 生成可独立运行的交互式 3D HTML：
- 鼠标拖动旋转
- 滚轮缩放
- 点击按钮切换模式
- Hover 查看数据

无需 Python / 服务器，本地浏览器直接打开。

## 3 个 HTML

| 文件 | 用途 |
|---|---|
| `interactive_5modes.html` | **主交互**：5 模式按钮切换轨迹（STRAIGHT / LEFT_CURVE / RIGHT_CURVE / TOPSPIN / BACKSPIN）|
| `interactive_default.html` | 默认直线球 3D 视图 |
| `propulsion_comparison.html` | 3 推进方式对比（tangent_friction / 8bar / 50m pneumatic）|

## 物理模型

- 球轨迹 = 抛物线 + 空气阻力（Cd=0.25）+ Magnus 效应
- Magnus 系数 k_lat=0.42（侧向）, k_vert=0.30（上下）
- 旋转 = 3 电机 RPM 差速
- 出膛速度 = 取决于推进方式：
  - `tangent_friction`：3 切向滚轮摩擦（≈3-5 m/s）
  - `pneumatic_8bar`：8 bar / 5 L / 200 mm（≈63 m/s）
  - `pneumatic_50m`：8 bar / 20 L / 400 mm（≈90 m/s）

## 重新生成

```bash
pip install plotly manifold3d
cd football-launcher-3d
python3 scripts/build_interactive_3d.py
```

## 本地查看

直接浏览器打开 HTML：

```bash
open cad/3d-print/interactive-3d-v22/interactive_5modes.html
```

## 控制操作

- 鼠标左键拖动：旋转视角
- 鼠标右键拖动：平移
- 滚轮：缩放
- 左上角按钮：切换模式 / 视角

## 已知限制

- Plotly HTML 单文件包含 Plotly.js（CDN）— 首次打开需联网
- 中文不在 Plotly 默认字体中（用英文标签）
- 旋转动画需要 JS（不在本版本）

## 进阶（未做）

- [ ] Slider 实时调 RPM
- [ ] 球沿轨迹动画（按帧）
- [ ] 视频导出
- [ ] 实测数据导入做校准

## 依赖

```bash
pip install plotly manifold3d matplotlib numpy
```

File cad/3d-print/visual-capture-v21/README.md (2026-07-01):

# Visual Capture + Control + Arc Simulation — v21

## 用途

一体化展示：
1. **3D 发射器渲染** + 实时轨迹
2. **控制参数面板**（3 电机 RPM、发射角、推进方式）
3. **5 种旋转模式弧线对比**（直线/左曲线/右曲线/上旋/下旋）

## 文件清单

| 文件 | 内容 |
|---|---|
| `visual_capture_v21.png` | **主综合图**：3D 发射器 + 控制面板 + 5 模式轨迹 |
| `control_adjustment_v21.png` | 控制调节对比（直线/左曲线/右曲线）|
| `arc_straight.png` | 直线球轨迹（独立大图）|
| `arc_left_curve.png` | 左曲线球轨迹 |
| `arc_right_curve.png` | 右曲线球轨迹 |
| `arc_topspin.png` | 上旋球轨迹（低平）|
| `arc_backspin.png` | 下旋球轨迹（高抛）|
| `visual_capture.py` | 重新生成脚本 |

## 5 模式配置

| 模式 | W1 RPM | W2 RPM | W3 RPM | 效果 |
|---|---|---|---|---|
| STRAIGHT | 2500 | 2500 | 2500 | 直线 |
| LEFT_CURVE  | 2300 | 2700 | 2500 | 向左偏 |
| RIGHT_CURVE | 2700 | 2500 | 2300 | 向右偏 |
| TOPSPIN | 2800 | 2400 | 2300 | 球加速下坠（低平）|
| BACKSPIN | 2300 | 2400 | 2800 | 球上飘（高抛）|

## 推进方式

- `tangent_friction`：3 切向滚轮摩擦驱动（v18 物理）
- `pneumatic_8bar`：8 bar 气压（主推）
- `pneumatic_8bar_50m`：8 bar / 20 L / 400 mm（50 m 目标）
- `manual`：手动设置出膛速度

## 控制参数

- 3 电机 RPM（每个独立）
- 发射角（默认 8°，轨迹图用 12°）
- 推进方式选择
- 出膛速度自动计算

## 重新生成

```bash
cd football-launcher-3d
python3 scripts/visual_capture.py
```

## 物理模型

球轨迹 = 抛物线 + 空气阻力 + Magnus 效应

```python
F_drag = 0.5 × ρ × Cd × A × v²
F_magnus_lat = k_lat × ω × v  (侧向)
F_magnus_vert = k_vert × ω × v  (上下)
```

系数（需现场校准）：
- ρ = 1.225 kg/m³
- Cd = 0.25（球）
- k_lat = 0.42, k_vert = 0.30

## 局限

- 中文字符显示为方框（matplotlib 缺中文字体）— 用英文标识
- Magnus 系数是经验值，需要实际校准
- 3D 渲染中轨迹和发射器比例可能不完美

## 后续

- 加交互式 HTML（Plotly）
- 加现场校准工作流
- 加视频帧序列（球动画）

## 依赖

```bash
pip install manifold3d matplotlib numpy
```

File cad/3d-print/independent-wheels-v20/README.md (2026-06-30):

# Independent Cradle Wheels Launcher — v20

## 修正（vs v19）

owner: "你的外圈加强设计并不符合图片"

参考图特征（核对清楚）：
- **每个 cradle 是独立轮**（不是连续外壳）
- **外圈厚环加强**（明显的轮辋结构）
- **3 条辐条清晰可见**（三角形开口）
- **4 颗 M5 螺栓固定到管**
- **中心 hub 容纳电机**

v19 错误：连续外壳（错误结构）
v20 修正：3 个独立轮辋（每个匹配参考图）

## 零件清单

| 文件 | 用途 | 数量 |
|---|---|---|
| `cradle_wheel_v20.stl` | **★ 独立 cradle 轮**（轮辋+辐条+hub）| 3 |
| `tube_v20.stl` | 简单管（球通道 + can 孔 + 螺母沉孔）| 1 |
| `side_plate_v20.stl` | 端板 | 2 |

## 几何（单个轮辋）

```
轮外径:    160.5mm
轮内径:    115.5mm（包管外侧）
环宽:      22.5mm
环厚:      14mm（加强）
Hub OD:    71mm
Hub 长度:   80mm（沿 Z 轴，容纳电机）
辐条:      3 条 120° 间隔
螺栓:      4×M5（外圈 PCD 138mm）
```

## 装配（3 轮独立）

```
                    球
                  ↗  ↓  ↖
              轮② can can 轮①
                ↑  ↓  ↑
              can     can
              can     can
              can     can
              轮③══════════轮③
                  ║  管  ║
                  ╚═════╝
```

每个轮独立件：
- 用 4 颗 M5 螺栓固定到管（管上预埋螺母）
- 电机 can 通过管壁孔接触球
- 电机轴切向（v18 物理）

## 打印

- 材料：PETG / ABS / CF-PETG
- 方向：管长竖直
- 3 个独立轮打印后装配

## 依赖

```bash
pip install manifold3d matplotlib
```

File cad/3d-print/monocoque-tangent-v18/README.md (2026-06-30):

# Monocoque Tangent-Roller Launcher — v18（正确几何）

## 核心修正

**电机轴 = 切向**（垂直于径向，也垂直于管轴 Z）

owner 三条指令合并：
- "恰恰有 90 度关系" → 电机轴垂直于管
- "三电机旋转与圆管径向相切" → 旋转切向
- "电机轴不平行于管" → 否定 v17 的平行假设

## 为什么这次能发射（力学证明）

电机在 0° 位置 (140.5, 0, 0)，轴沿切向 Y：
```
接触点 (109, 0, 0)（can 内缘，球面 110mm，1mm 压紧）
r = 接触点 - 轴位置 = (-31.5, 0, 0)
ω = (0, ω, 0)（切向）
v = ω × r = (0, 0, 31.5ω)  ← +Z 方向 = 发射方向！
```

3 电机 120° 同向旋转 → 都推球 +Z → **球被摩擦驱动沿管射出**
差速 → 弧线球 / 上下旋

## vs 之前所有版本

| 版本 | 电机轴 | 能否发射 |
|---|---|---|
| v1-v5, v11-v13 | 平行管 | ❌ 原地打转 |
| v6-v10, v14 | 径向 | ❌ Z 分量抵消 |
| v15-v17 | 平行管 | ❌ 原地打转 |
| **v18** | **切向** | ✅ **+Z 推出** |

## 几何

```
球:          220mm（R 110）
管内径:       113mm
管外径:       121mm
管长:         160mm
电机:         6374（can = 切向滚轮）
电机中心 R:   140.5mm
电机轴:       切向（每个 120° 位置的切线方向）
壳体外径:     184mm
支撑板:       每电机 2 块（can 切向两端，90° 于轴）
```

## 结构

```
        球（中心）
    can①↗   can②↘   ← 切向滚轮（轴 = 切线方向）
       ╲    │    ╱      can 滚动 → 推球 +Z
        支撑板（两端夹电机）
    ═══一体化壳体═══
```

- 每个电机 can 切向放置
- can 两端定子（出线侧）固定到支撑板
- 支撑板垂直于切向轴（90° 关系）
- 一体化壳体连接 3 组支撑

## 零件清单

| 文件 | 用途 | 数量 |
|---|---|---|
| `monocoque_v18.stl` | **★ 一体化壳体**（管+外环+6 支撑板+3 管壁槽）| 1 |
| `side_plate_v18.stl` | 端板 | 2 |

## 推进方式

**两种可选（已验证切向几何能发射）：**
1. **纯摩擦驱动**：3 切向滚轮直接驱动球（v18 几何支持）
2. **气压 + 控旋**：气压主推 + 切向滚轮控旋（更高速）

## 打印

- 材料：PETG / ABS / CF-PETG
- 方向：管长竖直
- 支撑板 + 管壁槽需支撑

## 依赖

```bash
pip install manifold3d matplotlib
```

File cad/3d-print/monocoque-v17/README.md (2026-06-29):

# Monocoque Launcher — v17（推倒重做）

## 设计要点（owner 全部要求）

1. **一体化壳体**（monocoque）— 不是分离臂+座
2. **电机外壳（外转子 can）直接当滚轮** — 无额外滚轮件
3. **电机两端固定到加强筋** — 两端支撑（非悬臂），刚性好
4. **加强筋 90° 于电机轴** — 端部垂直支撑（"90度关系"）
5. **静止出线侧固定于加强筋** — 定子/出线侧固定，can 中段转动
6. 气压主线（电机 = 控旋 / 控球）

## 几何

```
球:           220mm（R 110）
管内径:        113mm
管外径:        121mm
管长:          114mm（电机 74 + 两端筋空间）
电机:          6374（can = 滚轮）
电机中心 R:    140.5mm（球R - 1mm压紧 + can R）
can:          中段当滚轮，接触球
壳体外径:      182mm
加强筋厚:      18mm（两端各一）
出线口:        底部加强筋开槽
```

## 结构剖析

```
   顶部加强筋 ═══════════  ← 90° 端盘，固定电机上端定子
      ║  ▓can▓  ║          ← can 外转子（中段滚轮）
      ║  ▓can▓  ║             接触球，转动给旋
   底部加强筋 ═══════════  ← 90° 端盘，固定电机下端定子 + 出线口
        球（中心）
```

- 电机两端（静止定子）固定到上下加强筋
- can（外转子）在两筋之间转动
- can 中段通过管壁槽接触球
- 出线从底部加强筋引出

## 零件清单

| 文件 | 用途 | 数量 |
|---|---|---|
| `monocoque_v17.stl` | **★ 一体化壳体**（管+外环+两端加强筋+管壁槽）| 1 |
| `side_plate_v17.stl` | 端板（接气压端/出球端）| 2 |

## vs v16

| | v16 | v17 |
|---|-----|-----|
| 电机固定 | 单侧圆弧槽（悬臂）| **两端加强筋（双支撑）** |
| 刚性 | 一般 | **高** |
| 出线 | 未定义 | **底部加强筋引出** |
| 加强筋 | 无 | **90° 端盘 ×2** |

## 打印

- 材料：PETG / ABS / CF-PETG
- 方向：管长竖直（Z）
- 加强筋是端盘，电机从端部装入后固定
- 管壁槽需支撑

## 依赖

```bash
pip install manifold3d matplotlib
```

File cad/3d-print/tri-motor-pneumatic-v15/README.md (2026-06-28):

# Tri-Motor Pneumatic Launcher — v15

## 架构基础

按 `PROPULSION_ARCHITECTURE_REVIEW_V1.md` 锁定的主线方案：

- **压缩空气** = 主轴向推进（不再是三电机摩擦）
- **3 电机径向 cradle + 飞轮盘** = 控旋模块
- 阀、罐、压力表等 = 外购件，不 3D 打印

## 零件清单

| 文件 | 用途 | 数量 |
|---|---|---|
| `tube_body_v15.stl` | 主发射管（400mm + 4 条球导轨 + 装球口）| 1 |
| `pressure_end_v15.stl` | 压力端（封闭 + 进气口 + 爆破片槽）| 1 |
| `motor_cradle_v15.stl` | 控旋模块（盘状 cradle + 飞轮盘）| 3 |
| `output_end_v15.stl` | 前端出球口 + 安全网固定位 | 1 |

## 几何参数

```
球:           220mm
发射管:       IR 113 / OR 140 / L 400mm
管内:         4 条球导轨（让球居中）
装球口:       1/4 管长位置，侧面凸缘 + 闸门预留
压力端:       OR 155，法兰螺栓 8×M5
进气口:       φ25mm（接电磁阀）
爆破片槽:     环形槽（安全）
Cradle 中心:  125mm 半径（管外 55mm）
Cradle:       3 条辐条 120°，盘厚 10mm
飞轮盘:       φ50×8mm（接触球面）
出球端:       OR 160 + 外缘环
```

## 仿真支撑（`sim/pneumatic_launch_model.py`）

| 配置 | 出膛速度 | 射程 |
|---|---|---|
| 5 bar / 5 L / 200mm | 51 m/s | 48 m |
| 8 bar / 5 L / 200mm | 63 m/s | 68 m |
| **8 bar / 20 L / 400mm** | **90 m/s** | **80+ m** (50m目标) |
| 12 bar / 5 L / 200mm | 76 m/s | OVER-RATED |

## 安全边界（外购件配置）

- 工作压力 ≤ 8 bar
- 爆破片 @ 9.6 bar (1.2× 工作)
- 泄压阀 @ 8.8 bar (1.1× 工作)
- 急停按钮（硬件切断气源）
- 球装载互锁（球未到位禁加压）
- 操作员距离 ≥ 3m

## 3D 打印注意

- **不能 3D 打印压力容器** — 压力端仅作端盖，气罐外购
- 主体用 PETG / ABS / CF-PETG
- 球导轨需要支撑打印
- 飞轮盘精度高，需 0.15mm 层高

## 依赖

```bash
pip install manifold3d matplotlib
```

## 文件

- `params.py` — 参数化 STL 生成
- `render.py` — 组装图渲染
- `assembly_v15_iso.png` / `assembly_v15_side.png` — 组装图

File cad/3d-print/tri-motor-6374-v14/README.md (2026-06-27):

# Tri-Motor 6374 3D Printed Parts — v14 (CORRECTED: Radial + Flywheel Disc)

## 关键修正

**v6-v13 错误设计：**
- 电机轴向径向或平行于管，can 为圆柱壳
- Can 旋转产生的接触速度**无 Z 分量** → 球只绕管轴原地打转

**v14 正确设计：**
- 电机轴向**径向**（垂直于管）
- 端部装**平面飞轮盘**（盘面垂直于电机轴）
- 盘旋转产生的接触速度**有 Z 分量** → 球沿管射出

## 力学推导

电机轴沿径向（X），盘面在 YZ 平面：
- 盘面接触点 (x_c, y_c, z_c)，其中 y_c² + z_c² ≤ r_disc²
- 盘旋转 ω 在 +X 方向
- 接触点速度：v = ω × r = (0, -ω·z_c, ω·y_c)
- **Z 分量 v_z = ω·y_c**

3 个盘在 120° 分布，所有 Z 分量同向叠加：
- **净 Z 力 → 球沿管轴射出** ✓

## 几何参数

```
球:        220mm
管:        IR 113 / OR 140 / L 200mm
电机:      6374 × 3，轴向径向
飞轮盘:    50mm 直径 × 8mm 厚
盘 V 槽:    3 道 × 2mm 深
Cradle 中心: 125mm 半径（管外）
盘位置:    电机 +X 端外侧
```

## 零件清单

| 文件 | 用途 | 数量 |
|---|---|---|
| `spider_body_v14.stl` | **★ 主结构（管+3 cradle+3 飞轮盘）** | 1 |
| `side_plate_v14.stl` | 端板 | 2 |

## 打印

- 材料：PETG / ABS
- 方向：管长竖直
- 支撑：cradle 外侧需要

## 依赖

```bash
pip install manifold3d matplotlib
```

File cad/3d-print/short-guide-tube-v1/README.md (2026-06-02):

# Short Guide Tube v1 (3D Print Draft)

## Purpose
Short detachable guide tube for single-ball 3-wheel launcher.
Used only for short guidance / initial direction stabilization.
Not a feed tube, not a long barrel.

## Key dimensions
- Length: 200 mm
- Inner diameter: 232 mm
- Wall thickness: 4 mm
- Entry flare length: 35 mm
- Outer flange diameter: 270 mm
- Mount holes: 6 x M5 on PCD 252 mm

## Print suggestion
- Material: PETG / Nylon preferred
- Layer height: 0.24 mm
- Perimeters: 5+
- Infill: 35%+
- Print in 2 half-shells, then bolt together on flange if printer volume is limited

## Notes
- Keep inner wall smooth
- Do not let inner wall rub ball significantly
- Designed for A/B test against no-guide / 150mm / 250mm variants

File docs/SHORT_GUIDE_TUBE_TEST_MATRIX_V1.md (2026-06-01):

# 短导向筒 A/B 测试矩阵 v1

## 目标
评估短导向筒对以下指标的影响：
- 出球方向一致性
- 直射偏航
- 轻弧线稳定性
- 标准弧线稳定性
- 是否削弱旋转

## 测试变量
### 导向筒
- G0：无导向
- G1：150mm / Ø232
- G2：200mm / Ø232
- G3：250mm / Ø232

### 发射模式
- P1：`preset straight_pass`
- P2：`preset light_left_curve`
- P3：`preset light_right_curve`
- P4：`preset standard_left_curve`
- P5：`preset standard_right_curve`

## 测试矩阵
| Guide | Length | Preset | 目标 | 记录项 |
|---|---:|---|---|---|
| G0 | 0 | P1 | 直射基线 | 球速、偏航、落点 |
| G0 | 0 | P2 | 轻左弧线 | 球速、偏移、旋转方向 |
| G0 | 0 | P4 | 标准左弧线 | 球速、偏移、稳定性 |
| G1 | 150 | P1 | 比对直射稳定性 | 球速、偏航、落点 |
| G1 | 150 | P2 | 比对轻左弧线 | 球速、偏移、旋转方向 |
| G1 | 150 | P4 | 比对标准左弧线 | 球速、偏移、稳定性 |
| G2 | 200 | P1 | 比对直射稳定性 | 球速、偏航、落点 |
| G2 | 200 | P2 | 比对轻左弧线 | 球速、偏移、旋转方向 |
| G2 | 200 | P4 | 比对标准左弧线 | 球速、偏移、稳定性 |
| G3 | 250 | P1 | 比对直射稳定性 | 球速、偏航、落点 |
| G3 | 250 | P2 | 比对轻左弧线 | 球速、偏移、旋转方向 |
| G3 | 250 | P4 | 比对标准左弧线 | 球速、偏移、稳定性 |

## 最小记录表
| Guide | Preset | wheel1/2/3 target | 球速 | 横向偏移 | 落点偏差 | 是否打滑 | 是否削弱旋转 |
|---|---|---|---|---|---|---|---|
|  |  |  |  |  |  |  |  |

## 判定原则
### 导向筒保留
满足至少两条：
1. 直射偏航更小
2. 落点离散度更小
3. 轻弧线可重复性更高
4. 标准弧线没有明显被削弱

### 导向筒淘汰
任一明显出现：
1. 球速明显下降
2. 旋转效果被明显削弱
3. 球面摩擦痕迹明显
4. 偏航反而更大

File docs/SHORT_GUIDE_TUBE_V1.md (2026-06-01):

# 短导向筒尺寸草案 v1

## 设计边界
- 允许：短导向结构，用于上球定位、初始方向稳定
- 不允许：供球管、长管膛、多球导槽
- 不允许：明显摩擦球面，破坏旋转
- 要求：可拆卸，便于 A/B 测试

## 建议尺寸
- 长度：150 ~ 250mm
- 首版建议：200mm
- 内径：230 ~ 235mm
- 首版建议：232mm
- 与球总间隙：约 5 ~ 7.5mm

## 结构建议
- 入口：喇叭口过渡
- 中段：短直筒
- 出口：圆角收边
- 材料：UHMWPE / HDPE / 尼龙 / 光滑 PC 内衬

## A/B 测试组合
1. 无导向
2. 150mm
3. 200mm
4. 250mm

## 验证项
- 出球方向一致性
- 直射偏航
- 轻弧线 / 标准弧线稳定性
- 是否削弱旋转

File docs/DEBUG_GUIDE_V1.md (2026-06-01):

# 调试手册 v1

> 目标：让 `ESP32-S3 Host + B-G431B-ESC1 ×3` 的单球三轮发射器在 P0 阶段更容易定位问题。

## 1. 先看什么
### 第一优先
1. Host 是否启动
2. 3 个 Node 是否都在线
3. nodeId 是否和物理轮位一致
4. `SET_RPM` 是否发出
5. `STATUS / HEARTBEAT` 是否回传

### 第二优先
1. wheel1/2/3 的 `targetRpm`
2. wheel1/2/3 的 `actualRpm`
3. `faultCode`
4. `busVoltage`
5. `phaseCurrent`
6. `temp`

## 2. 轮位映射检查
固定映射：
- wheel1 -> 12:00 -> `NODE_ID_WHEEL_A (0x11)`
- wheel2 -> 4:00  -> `NODE_ID_WHEEL_B (0x12)`
- wheel3 -> 8:00  -> `NODE_ID_WHEEL_C (0x13)`

### 检查方法
1. 只给 `wheel1` 一个低速目标 rpm
2. 看转的是不是 12 点钟那一路
3. 再分别测 wheel2 / wheel3

如果转错：
- 先检查板子烧录的 nodeId
- 再检查 Host 物理接线记录
- 不先改 mixer 公式

## 3. 最小 bring-up 顺序
### Step 1
Host 上电：
- 看 boot log
- 看 CAN init

### Step 2
单个 Node 上电：
- 看 `STATUS`
- 看 `HEARTBEAT`
- 看 `faultCode == 0`

### Step 3
三节点同时在线：
- A/B/C 都能回包
- nodeId 不冲突

### Step 4
单轮低速目标：
- `500 rpm`
- 再 `1000 rpm`
- 再 `2000 rpm`

### Step 5
三轮同 rpm：
- 先 `STRAIGHT`
- 再 `TOPSPIN`
- 再 `LEFT_CURVE`

## 4. 常见故障定位
### A. Host 发了，Node 不动
先查：
1. CAN 收发
2. nodeId 是否匹配
3. Node 是否进入 `ESTOP/FAULT`
4. `enabled` 是否被拉低

### B. targetRpm 正常，actualRpm 不上来
先查：
1. 电机相线 / Hall 线
2. Node 当前限流
3. 驱动故障脚
4. 轮组是否机械卡滞

### C. 三轮转了但球偏航严重
先查：
1. 轮位映射是否搞错
2. 三轮预压是否一致
3. 轮面材料是否一致
4. 实际 rpm 偏差是否过大

### D. 一启动就 fault
先查：
1. 电源压降
2. 总保险 / 支路保险
3. 驱动过流 / 过温
4. 急停链路是否误触发

## 5. 推荐日志字段
### Host
- `state`
- `spinMode`
- `ballLoaded`
- `wheel1 actual/target`
- `wheel2 actual/target`
- `wheel3 actual/target`
- `hostFault`

### Node
- `nodeId`
- `state`
- `enabled`
- `targetRpm`
- `actualRpm`
- `busVoltage`
- `phaseCurrent`
- `temp`
- `faultCode`

## 6. 调试原则
1. 一次只改一个变量
2. 先单轮，再三轮
3. 先低 rpm，再高 rpm
4. 先直射，再旋转
5. 先看日志，再改参数

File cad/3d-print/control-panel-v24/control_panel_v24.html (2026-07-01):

LAUNCH CONTROL

模式直线球

电量82%

温度36℃

视觉OK

当前发射状态

发射状态

未就绪

等待系统就绪

当前模式

直线球

点击下方按钮切换

气压

0.62

MPa · 8 bar 标称

模式选择

→直线

↙左弧

↘右弧

↓上旋

↑下旋

⚙自定义

发射控制

🚀 发射 ⏳ 待确认 试射一次

🔒 系统锁定 解除锁定 ⛔ 急停

轨迹视图 (180° 发射扇区)

预测弧线

实测弧线

目标落点

偏差超限

落点数据

预测落点

23.4 m

横向 -2.1 m

实测落点

21.9 m

横向 -3.0 m

偏差分析

距离偏差

-1.5 m

横向偏差

-0.9 m

🔄 回填参数 清除本次

⚠ 参数已修改，需要确认才能发射

三电机 RPM

电机 A (0°)

2500

电机 B (120°)

2500

电机 C (240°)

2500

推进参数

气压

0.62 MPa

阀门延迟

12 ms

活塞力度

75%

弧线 / 旋转

左右弧线强度

0%

上/下旋强度

0%

✓ 确认参数 💾 保存预设 ↻ 恢复默认

系统总览

总体状态

正常

⚠ 当前错误

🔄 重新检测 🔧 电机同步 ⛔ 解除故障

子系统诊断

摄像头

正常

60 FPS

置信度 92%

电机 A

正常

4180 rpm

42 ℃

电机 B

正常

3910 rpm

44 ℃

电机 C

警告

4020 rpm

48 ℃

气压系统

正常

0.62 MPa

漏率 0.02 bar/s

电磁阀

正常

延迟 12 ms

发射次数 47

电池

正常

82%

24.1 V

首页

弧线

参数

诊断

发射

未就绪

锁定

LOCKED

急停

正常

电量

82%

⛔ EMERGENCY STOP

## ⛔ 确认急停？

急停会立即切断所有电源，
需要人工复位才能恢复。

取消 确认急停

## ⚠ 高压确认

当前气压设定值已超过安全阈值 (0.85 MPa)。
请确认发射环境已清场。

取消 我已确认

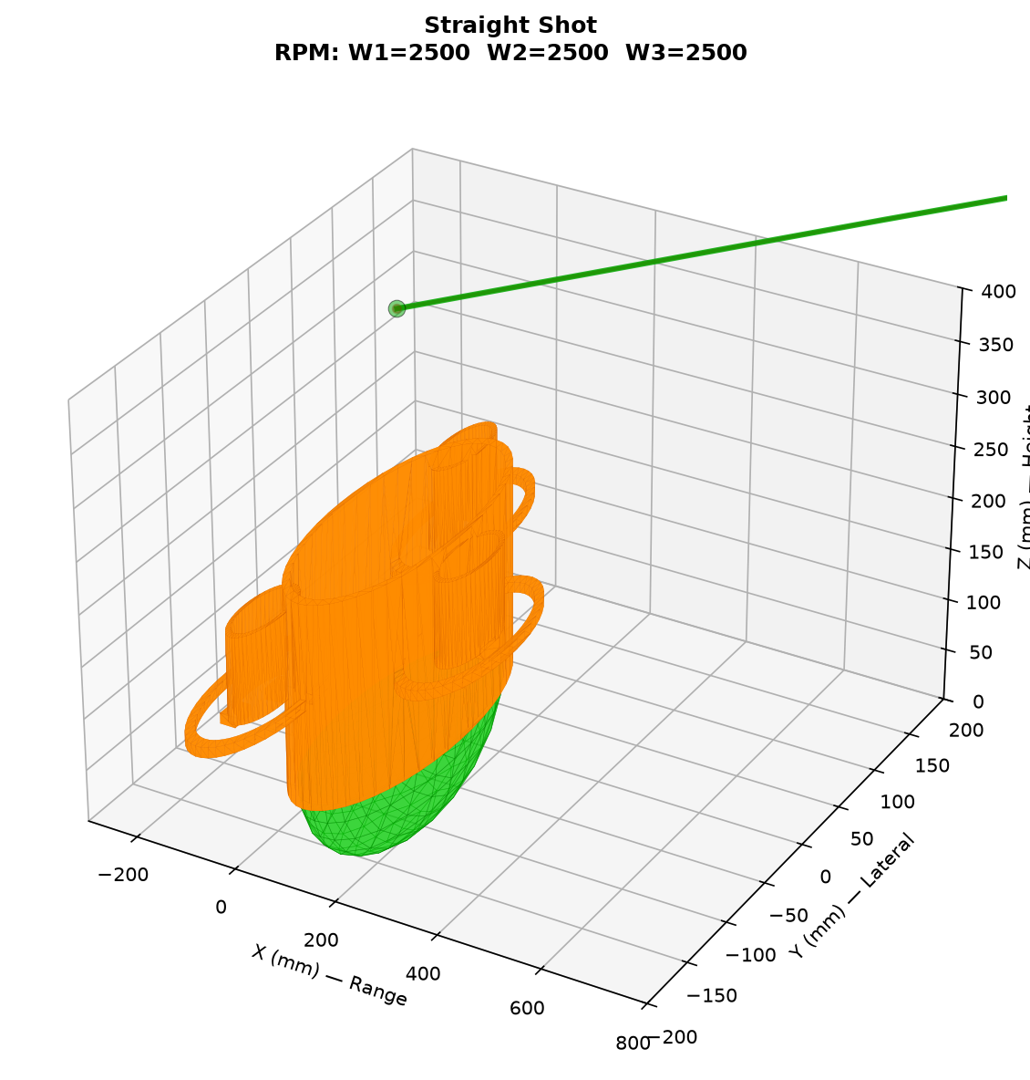
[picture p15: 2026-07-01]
cad/3d-print/visual-capture-v21/arc_straight.png

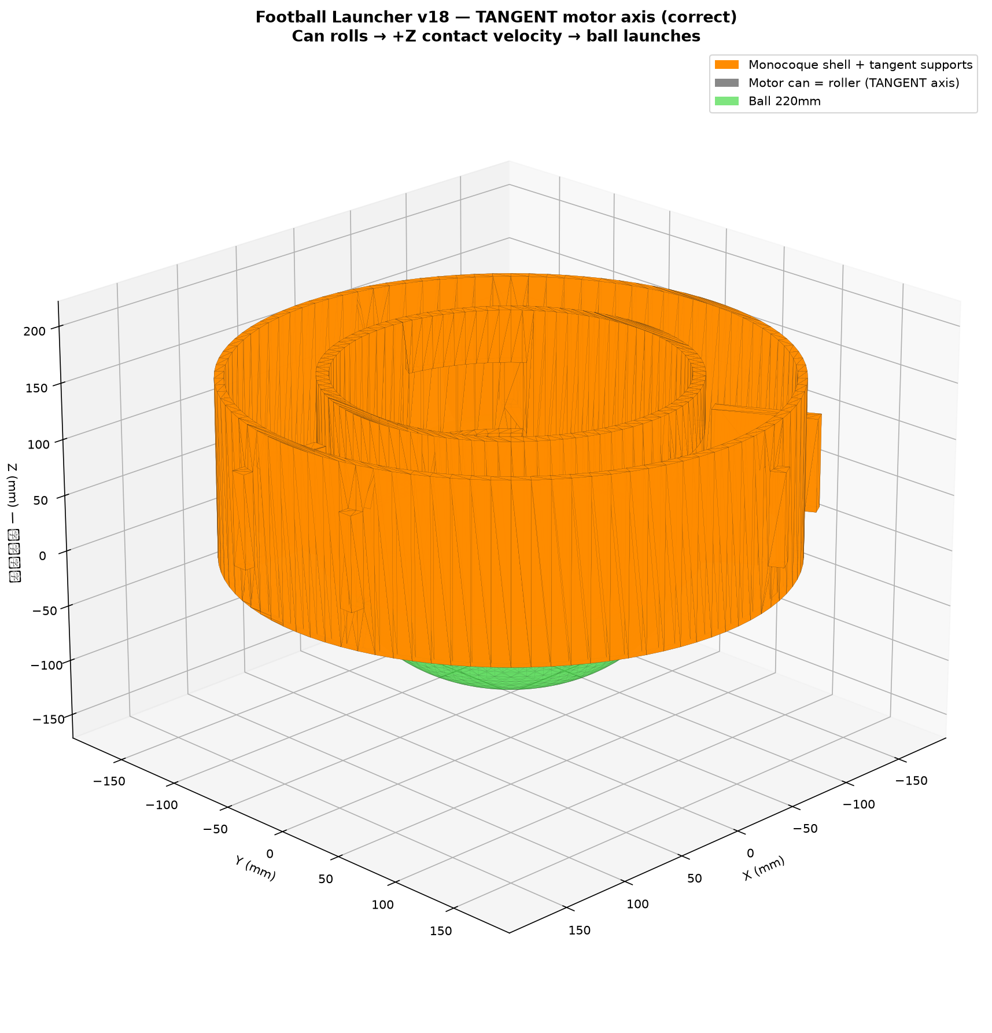
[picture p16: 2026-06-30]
cad/3d-print/monocoque-tangent-v18/assembly_v18_iso.png

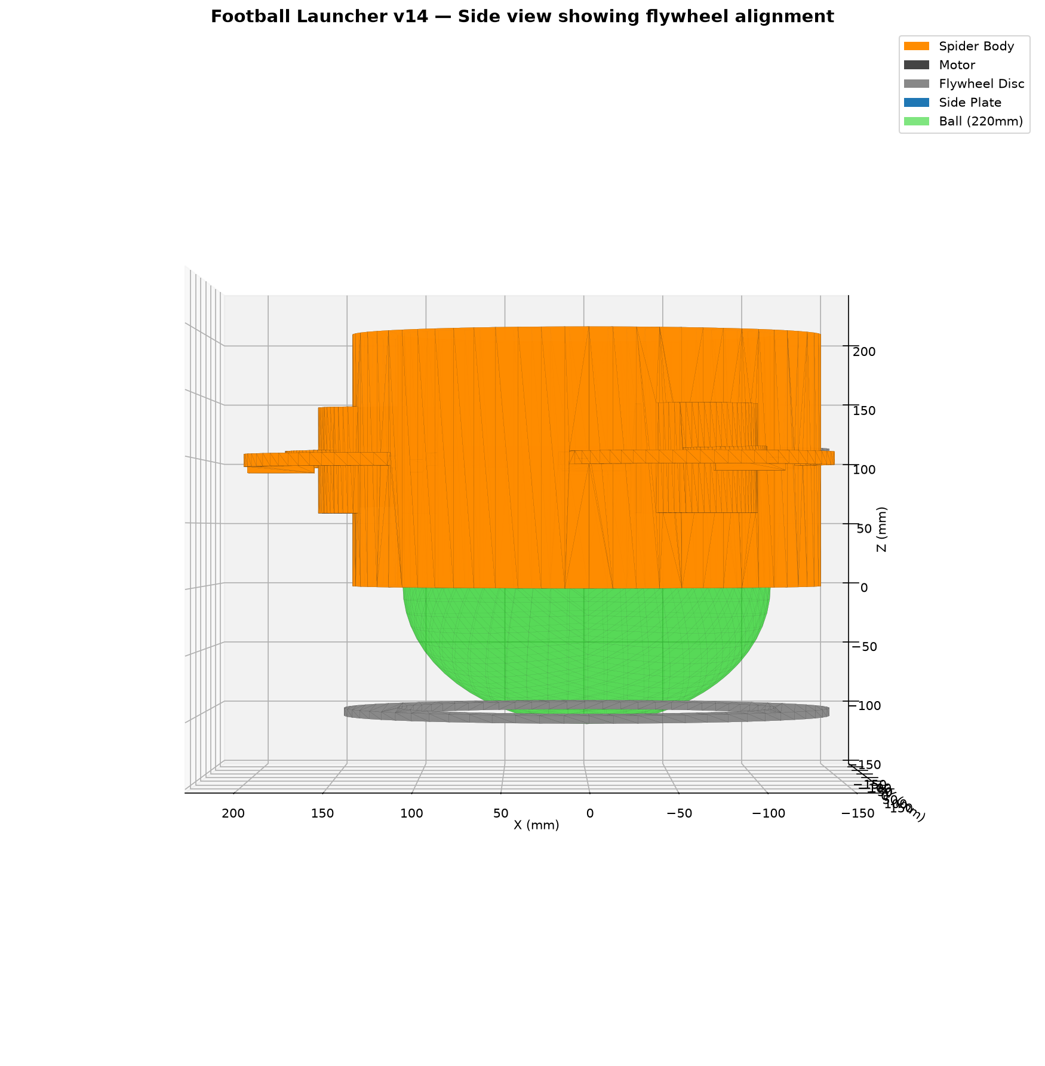
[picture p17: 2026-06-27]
cad/3d-print/tri-motor-6374-v14/assembly_v14_side.png

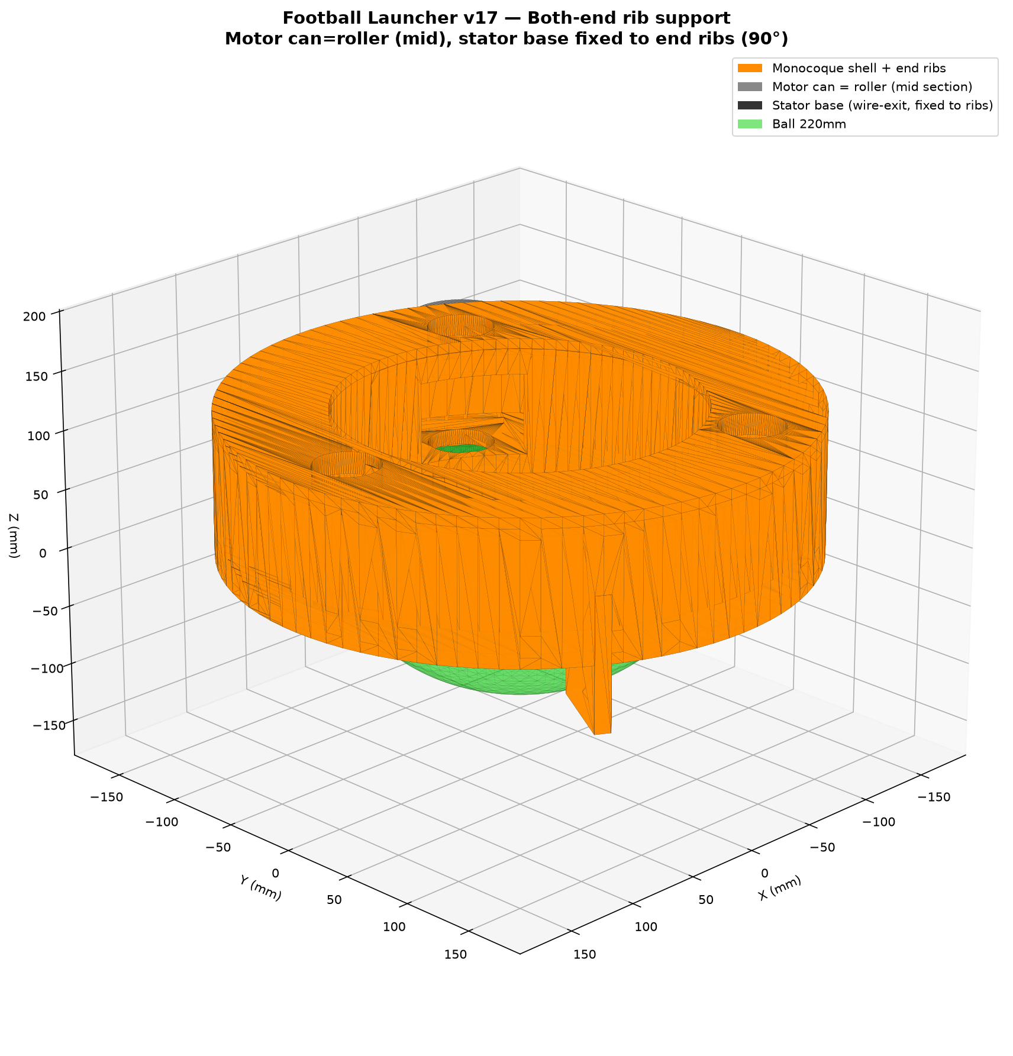
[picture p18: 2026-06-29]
cad/3d-print/monocoque-v17/assembly_v17_iso.png

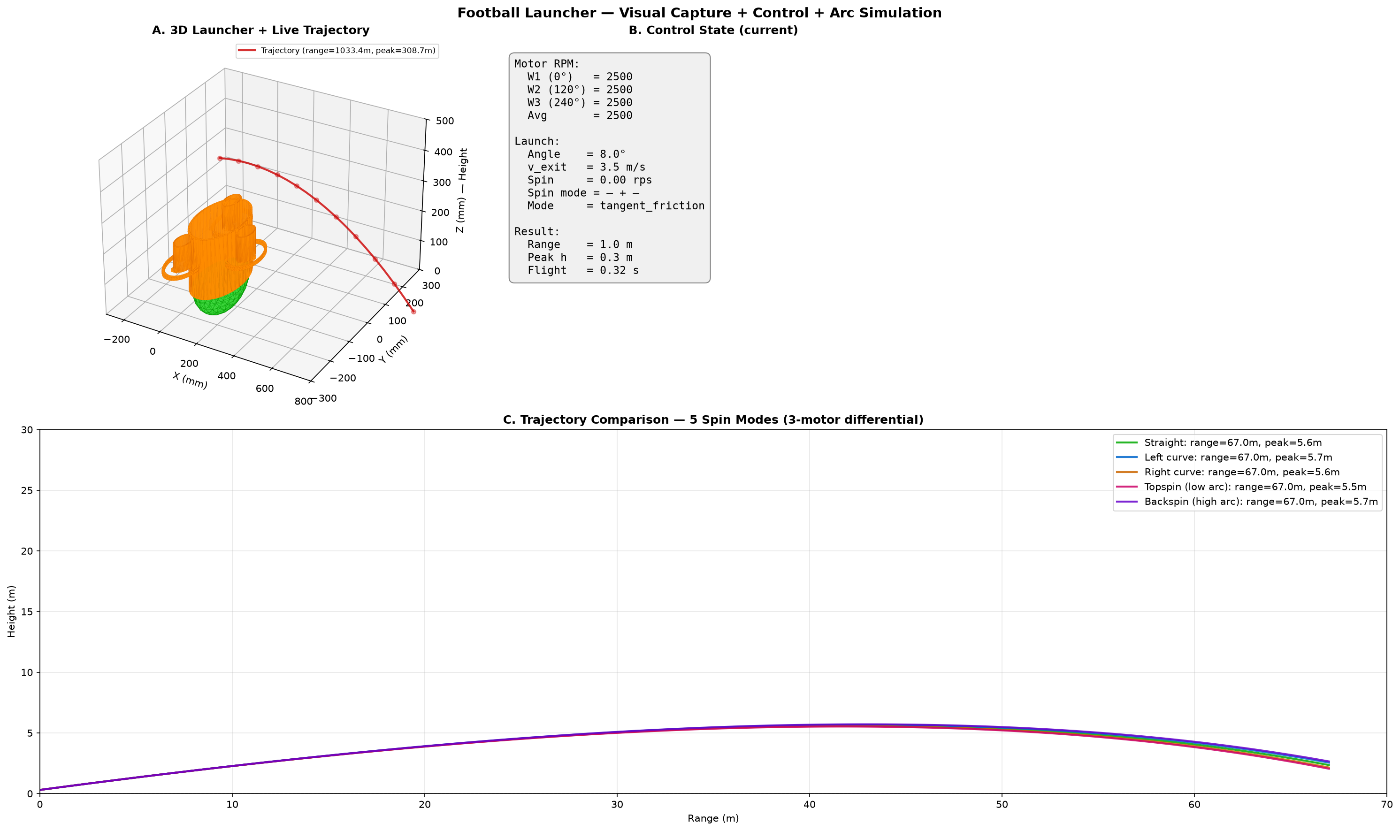
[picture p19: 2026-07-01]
cad/3d-print/visual-capture-v21/visual_capture_v21.png

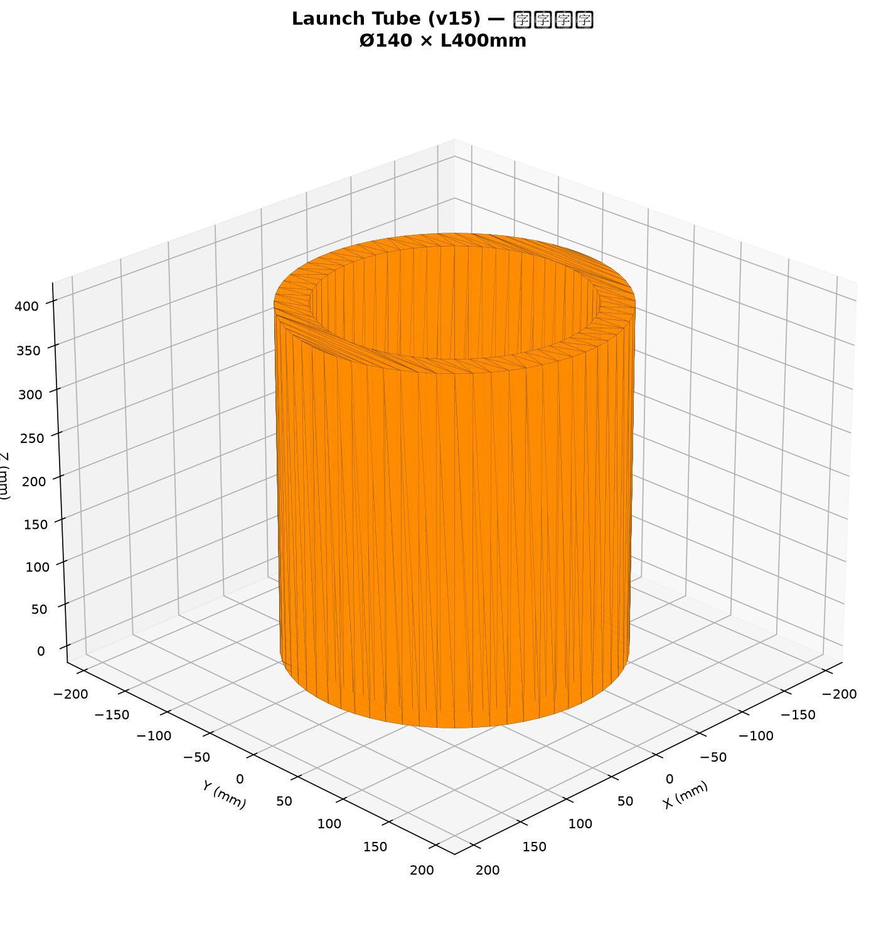
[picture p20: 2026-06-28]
cad/3d-print/tri-motor-pneumatic-v15/structure/tube_only_v15.png

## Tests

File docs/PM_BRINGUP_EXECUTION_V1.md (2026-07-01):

# P0-A Bring-up 执行手册 v1

> 由 Mia｜PM 整合，基于 firmware bring-up plan、hardware docs、procurement checklist。
> 最后更新：2026-07-01

## 前置条件

| # | 条件 | 状态 |
|---|---|---|
| 1 | P0-A 物料到位 | ⏳ 采购中 |
| 2 | 固件代码编译通过 | ✅ 代码库已有 |
| 3 | 结构 v12 CAD 定型 | ✅ `cad/3d-print/tri-motor-6374-v12/` |
| 4 | PCB 打样完成 | ⏳ 待打样 |

## 执行顺序

### 阶段 1：最小 Host 固件（无外设）

**目标**：ESP32-S3 跑起来，串口能打印，CAN 能初始化

| 步骤 | 动作 | 验收 | 参考 |
|---|---|---|---|
| 1.1 | 烧录 host-esp32s3 固件 | SWD 下载成功 | `firmware/host-esp32s3/` |
| 1.2 | 连接串口查看 boot log | 打印版本号 + 初始化日志 | `docs/DEBUG_GUIDE_V1.md` |
| 1.3 | 检查 CAN 初始化 | CAN 控制器进入正常模式 | `docs/CAN_PROTOCOL_V1.md` |
| 1.4 | GPIO 轮询传感器输入 | ball_present / exit_detect / estop 状态可见 | `docs/SENSOR_LAYOUT.md` |

**通过标准**：串口有 boot log，GPIO 状态变化可见，CAN 正常模式。

### 阶段 2：最小 Node 固件（无电机）

**目标**：STM32G431 跑起来，Driver 不报错，ADC 能读

| 步骤 | 动作 | 验收 | 参考 |
|---|---|---|---|
| 2.1 | 烧录 node-bg431b-esc1 固件 | SWD 下载成功 | `firmware/node-bg431b-esc1/` |
| 2.2 | 上电检查 3.3V / VBUS | 电压值合理 | `hardware/pinout/MOTOR_NODE_PINOUT.md` |
| 2.3 | 检查 Driver FAULT_N | 无误报 fault | `docs/FIRMWARE_BRINGUP_CHECKLIST.md` |
| 2.4 | 检查 VBUS_SENSE ADC | 读数合理 | — |

**通过标准**：下载正常，Driver 无 fault，VBUS 读数合理。

### 阶段 3：Hall 读取

**目标**：手转电机时能读到正确的 Hall 状态和转速

| 步骤 | 动作 | 验收 | 参考 |
|---|---|---|---|
| 3.1 | 连接 Hall 线束到 Node | 物理连接完成 | `hardware/pinout/CONNECTOR_TABLE.md` |
| 3.2 | 手转电机，观察 Hall 状态 | A/B/C 相序正确变化 | `docs/FIRMWARE_BRINGUP_PLAN.md` Phase 2 |
| 3.3 | 验证转速计算 | rpm 数值连续、无乱跳 | — |

**通过标准**：手转电机时 Hall 状态正确，转速连续。

### 阶段 4：Driver PWM + 单电机开环

**目标**：PWM 波形正常，电机能低速转动

| 步骤 | 动作 | 验收 | 参考 |
|---|---|---|---|
| 4.1 | 脱开电机负载，验证 PWM | 示波器看到 3 路 PWM | `docs/FIRMWARE_BRINGUP_PLAN.md` Phase 3 |
| 4.2 | 验证 enable/fault 联锁 | DRV_EN 可控，fault 后 PWM 关断 | — |
| 4.3 | 接上电机，开环低速测试 | 电机低速平稳转动 | Phase 4 |
| 4.4 | 检查限流/限速 | 无异常发热、无明显振动 | — |

**通过标准**：PWM 正常，电机低速可控，无异常。

### 阶段 5：单电机速度闭环

**目标**：500–3000rpm 速度闭环稳定

| 步骤 | 动作 | 验收 | 参考 |
|---|---|---|---|
| 5.1 | 切换到 velocity loop | SET_RPM 生效 | `docs/FIRMWARE_BRINGUP_PLAN.md` Phase 5 |
| 5.2 | 500rpm 测试 | 稳态误差 ±3% | — |
| 5.3 | 1000/2000/3000rpm 递增 | 各转速稳定 | — |
| 5.4 | 急停测试 | 急停后安全停机 | `docs/FAULT_SAFETY_CHAIN.md` |

**通过标准**：目标转速可跟踪，稳态误差 ±3%，急停有效。

### 阶段 6：Host ↔ Node 联调

**目标**：Host 可下发 RPM，Node 回传状态，超时保护生效

| 步骤 | 动作 | 验收 | 参考 |
|---|---|---|---|
| 6.1 | Host 发 SET_RPM，Node 响应 | Node 转速跟随 Host 指令 | `docs/CAN_PROTOCOL_V1.md` |
| 6.3 | Node 周期发 STATUS/HEARTBEAT | Host 收到状态帧 | `docs/FIRMWARE_COMM_LOOP.md` |
| 6.3 | 拔掉 CAN 线 | 系统进入 FAULT 保护 | `docs/FAULT_SAFETY_CHAIN.md` |

**通过标准**：通信正常，超时保护生效。

### 阶段 7：三 Node 联调

**目标**：三轮同步启动，轮间偏差 < 150ms

| 步骤 | 动作 | 验收 | 参考 |
|---|---|---|---|
| 7.1 | 三节点同时上线 | 三节点 CAN 帧均可见 | `docs/HOST_3NODE_INTEGRATION_DEMO_V1.md` |
| 7.2 | 三轮同步启动 | 90% 目标转速时间差 < 150ms | `docs/RPM_MIXER_120DEG.md` |
| 7.3 | 轮间偏差记录 | 偏差在目标范围内 | — |

**通过标准**：三轮同步，偏差 < 150ms。

### 阶段 8：发射状态机 + 低速射球

**目标**：手动上球 → 检测 → 发射 → 出球完整链路

| 步骤 | 动作 | 验收 | 参考 |
|---|---|---|---|
| 8.1 | 状态机代码验证 | IDLE→SPINUP→READY→FIRE→COOLDOWN 跑通 | `firmware/host-esp32s3/src/launch_state_machine.cpp` |
| 8.2 | 球检测传感器验证 | 手动放球检测正确 | `docs/SENSOR_LAYOUT.md` |
| 8.3 | 无球禁止发射 | ball_present=0 时禁止 FIRE | `docs/FEED_STATE_MACHINE_V1.md` |
| 8.4 | 低速单球射出 | 单次稳定射出标准 5 号球 | — |
| 8.5 | 出球超时保护 | 超时后进入 FAULT | — |

**通过标准**：手动上球可稳定射出，无球不能发射，超时保护有效。

### 阶段 9：15~20m 长传验证

**目标**：达到目标射程，记录数据回填仿真

| 步骤 | 动作 | 验收 | 参考 |
|---|---|---|---|
| 9.1 | 逐步提升转速 | 500→1000→1500→2000rpm | — |
| 9.2 | 记录射程/精度 | 每档转速至少 5 次 | `docs/P0_FIELD_TEST_LOG_TEMPLATE_V2.md` |
| 9.3 | 数据回填仿真 | `sim/football_launch_model.py` 参数更新 | `sim/` |
| 9.4 | 安全件全程到位 | 防护罩 + 急停 + 人员远离射出方向 | `docs/SAFETY` |

**通过标准**：15~20m 射程达成，数据有记录。

## 关键文档索引

| 文档 | 用途 |
|---|---|
| `docs/FIRMWARE_BRINGUP_PLAN.md` | 固件分阶段计划 |
| `docs/FIRMWARE_BRINGUP_CHECKLIST.md` | 固件验收清单 |
| `docs/CAN_PROTOCOL_V1.md` | CAN 通信协议 |
| `docs/FAULT_SAFETY_CHAIN.md` | 故障保护链路 |
| `docs/SENSOR_LAYOUT.md` | 传感器布局 |
| `docs/DEBUG_GUIDE_V1.md` | 调试指南 |
| `docs/P0A_TEST_KANBAN_V1.md` | P0-A 测试看板 |
| `docs/procurement/PROCUREMENT_P0A_V2.md` | 采购清单 |
| `cad/3d-print/tri-motor-6374-v12/` | 结构 CAD v12 |
| `hardware/FIRST_SPIN_BRINGUP.md` | 首版上电注意事项 |

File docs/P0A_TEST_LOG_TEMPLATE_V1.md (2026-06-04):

# P0-A 测试记录表 v1

## 测试信息

| 项 | 内容 |
|---|---|
| 日期 |  |
| 测试人 |  |
| 场地 | 台架 / 室内 / 球场 |
| 轮径 | 110mm / 130mm |
| 预压缩量 |  mm |
| 电源 | 24V 台架 / 电池 |
| 防护罩 | 已安装 / 未安装 |
| 急停 | 已验证 / 未验证 |

## A. 单电机闭环

| caseId | wheel | targetRpm | actualRpm 稳态 | 误差 | 峰值电流 | 温升 | 结果 | 备注 |
|---|---|---:|---:|---:|---:|---:|---|---|
| M1-500 | wheel1 | 500 |  |  |  |  |  |  |
| M1-1000 | wheel1 | 1000 |  |  |  |  |  |  |
| M1-2000 | wheel1 | 2000 |  |  |  |  |  |  |
| M1-3000 | wheel1 | 3000 |  |  |  |  |  |  |

复制到 wheel2 / wheel3。

## B. 三轮同步空载

| caseId | targetRpm | wheel1 90%时间 | wheel2 90%时间 | wheel3 90%时间 | 最大差值 | 峰值总电流 | 结果 |
|---|---:|---:|---:|---:|---:|---:|---|
| S-1000 | 1000 |  |  |  |  |  |  |
| S-2000 | 2000 |  |  |  |  |  |  |
| S-3000 | 3000 |  |  |  |  |  |  |

验收：90% 目标转速时间差 `<150ms`。

## C. 安全保护

| caseId | 测试项 | 触发方式 | 预期 | 实际 | 结果 |
|---|---|---|---|---|---|
| SAFE-ESTOP | 急停 | 运行中拍下 | 立即切 EN / 主动力 |  |  |
| SAFE-COMM | 通信断开 | 拔 CAN / 停 Host | 进入 FAULT |  |  |
| SAFE-NOBALL | 无球禁止发射 | ball_present=0 | 禁止 FIRE |  |  |
| SAFE-FAULT | 单节点 fault | 模拟 node fault | 全系统停机 |  |  |

## D. 低速实球

| caseId | wheel1 | wheel2 | wheel3 | 出球速度 | 射程 | 横向偏移 | 电流峰值 | 球面磨损 | 结果 |
|---|---:|---:|---:|---:|---:|---:|---:|---|---|
| B1 | 1000 | 1000 | 1000 |  |  |  |  |  |  |
| B2 | 1500 | 1500 | 1500 |  |  |  |  |  |  |
| B3 | 2000 | 2000 | 2000 |  |  |  |  |  |  |
| B4 | 2600 | 2600 | 2600 |  |  |  |  |  |  |

## E. 轻弧线

| caseId | wheel1 | wheel2 | wheel3 | 出球速度 | 射程 | 横向偏移 | 自旋方向 | 电流峰值 | 结果 |
|---|---:|---:|---:|---:|---:|---:|---|---:|---|
| C1 | 2600 | 2850 | 2350 |  |  |  |  |  |  |

## 回填仿真

| 参数 | 实测值 | 用途 |
|---|---:|---|
| 实际出球速度 / 仿真出球速度 |  | 修正接触效率 |
| 实际横向偏移 / 仿真横向偏移 |  | 修正 Magnus 系数 |
| 实测峰值电流 |  | 修正电源保护 v1 |
| 最佳预压缩量 |  | 修正机械设计 |

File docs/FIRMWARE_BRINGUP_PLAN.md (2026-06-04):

# 固件 Bring-up 计划 v1

> 目标：让硬件首版上电流程和固件动作一一对应，先跑通单电机闭环，再扩到三节点联调。

## Phase 0 - Host 板最小固件
### 目标
- ESP32-S3 可启动
- 串口日志正常
- 传感器 GPIO 可读
- CAN 初始化成功

### 固件动作
1. 上电打印版本号
2. 初始化 GPIO / UART / CAN
3. 轮询 `ball_present / exit_detect / estop`
4. 周期输出状态帧

### 验收
- 串口可见 boot log
- GPIO 状态变化可见
- CAN 控制器进入正常模式

---

## Phase 1 - Motor Node 最小固件（无电机）
### 目标
- STM32G431 可下载
- Driver 使能脚受控
- Driver fault 可读
- ADC 可读 VBUS

### 固件动作
1. 初始化时钟 / GPIO / ADC / CAN
2. 默认 `DRV_EN=0`
3. 读取 `DRV_FAULT_N`
4. 读取 `VBUS_SENSE`
5. 上报基础 `STATUS`

### 验收
- SWD 下载正常
- 串口/调试口可看状态
- Driver 不误报 fault
- VBUS 读数合理

---

## Phase 2 - Hall 读取
### 目标
- Hall A/B/C 相序正确
- 手转电机时能输出转速/方向

### 固件动作
1. 配置 Hall 输入中断/捕获
2. 输出原始 Hall 状态
3. 计算 electrical state / rpm
4. 上报 `actualRpm`

### 验收
- 手转电机时 Hall 状态变化正确
- 转速数值连续、无明显乱跳

---

## Phase 3 - Driver PWM 输出（脱开电机负载谨慎验证）
### 目标
- PWM 波形正常
- enable/fault 联锁正常

### 固件动作
1. 初始化 PWM timer
2. 仅在安全条件满足时拉高 `DRV_EN`
3. 输出低占空测试 PWM
4. fault 触发即关断

### 验收
- 示波器看到 3 路 PWM
- `DRV_EN` 可控
- fault 后 PWM 关闭

---

## Phase 4 - 单电机开环低速
### 目标
- 电机可低速平稳转动
- Hall 与方向一致

### 固件动作
1. 初始化 SimpleFOC 基础对象
2. 使用开环/低风险模式启动
3. 限速、限流、限加速度
4. 实时打印 rpm / fault

### 验收
- 电机低速可控
- 无异常发热、无明显振动

---

## Phase 5 - 单电机速度闭环
### 目标
- 达到 P0 单轮闭环范围 `500~3000 rpm`
- 空载误差满足预期

### 固件动作
1. 切换到 velocity loop
2. 配置基础 PID
3. 支持 `SET_RPM`
4. 周期上报 `STATUS`

### 验收
- 目标转速可跟踪
- 空载稳态误差约 `±3%`

---

## Phase 6 - Host ↔ 单 Node 联调
### 目标
- Host 可下发目标 RPM
- Node 可回传状态
- 通信超时可保护

### 固件动作
1. Host 发 `SET_RPM`
2. Node 收到后更新目标
3. Node 定期发 `STATUS/HEARTBEAT`
4. Host 监测超时转 `FAULT`

### 验收
- Host 改目标时 Node 行为正确
- 拔掉通信后系统进入保护

---

## Phase 7 - 三 Node 联调
### 目标
- 三轮同步启动
- 120° RPM mixer 生效

### 固件动作
1. Host 下发三节点不同目标 RPM
2. 检查同步启动时延
3. 记录轮间偏差

### 验收
- 三轮 90% 目标转速时间差 `< 150ms`

---

## Phase 8 - 单球手动上球 / 发射状态机
### 目标
- 手动放球后才允许发射
- 无球不发
- 出球检测 / 超时保护完整

### 固件动作
1. Host 状态机接入 `ball_present / exit_detect / estop`
2. `IDLE -> SPINUP -> READY -> FIRE -> COOLDOWN -> IDLE`
3. `ball_present=0` 时禁止进入 `FIRE`
4. 发射超时 / 出球未检测进入 `FAULT`

### 验收
- 手动上球检测正确
- 无球不能发射
- 出球检测或超时保护有效

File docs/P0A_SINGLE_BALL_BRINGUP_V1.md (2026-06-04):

# P0-A 单球台架 Bring-up 流程 v1

## 目标

在不追求高功率的前提下，验证：

1. 单电机 SimpleFOC 速度闭环。
2. 三电机同步预转。
3. 急停 / 故障保护。
4. 单球低速稳定射出。
5. 采集第一批实测数据回填仿真模型。

## 阶段 0：安全准备

- 防护罩安装完成。
- 急停按钮可触达。
- 发射方向无人。
- 台架电源限流打开。
- 不装球。

## 阶段 1：单电机空载

| 步骤 | 目标 | 验收 |
|---|---|---|
| M1-500 | wheel1 500rpm | 稳态误差 < ±5% |
| M1-1000 | wheel1 1000rpm | 无异常振动/发热 |
| M1-2000 | wheel1 2000rpm | 电流可控 |
| M1-3000 | wheel1 3000rpm | 仅短时验证 |

wheel2 / wheel3 重复同样流程。

## 阶段 2：三轮同步空载

| 步骤 | 目标 | 验收 |
|---|---|---|
| S-1000 | 三轮 1000rpm | 90% 目标转速时间差 < 150ms |
| S-2000 | 三轮 2000rpm | 无 fault |
| S-3000 | 三轮 3000rpm | 短时，记录峰值电流 |

## 阶段 3：急停 / 故障

- 运行中拍急停：驱动 EN 立即切断。
- 通信断开：进入 FAULT。
- 任一 node fault：Host 停止发射。
- 无球检测：禁止 FIRE。

## 阶段 4：低速实球

| 档位 | RPM | 目标 |
|---|---:|---|
| B1 | 1000/1000/1000 | 观察夹持/打滑 |
| B2 | 1500/1500/1500 | 低速出球 |
| B3 | 2000/2000/2000 | 记录出球速度 |
| B4 | 2600/2600/2600 | 对齐仿真 straight_pass |

## 阶段 5：轻弧线

仅在直传稳定后执行：

- `wheel1=2600`
- `wheel2=2850`
- `wheel3=2350`

记录横向偏移、球面磨损、电流峰值。

## 必记录数据

| 数据 | 用途 |
|---|---|
| wheel1/2/3 actualRpm | 检查负载掉速 |
| 单路电流峰值 | 修正电源保护 |
| 出球速度 | 回填接触效率 |
| 横向偏移 | 回填 Magnus 系数 |
| 预压缩量 | 找稳定区间 |
| 球面磨损/温升 | 安全评估 |

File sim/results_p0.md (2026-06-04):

# P0 Simulation Results v1

Generated by `sim/football_launch_model.py` using nominal assumptions:

- friction coefficient: 0.65
- preload: 10 mm
- ramp: 5 s
- wheel diameter: 110 mm
- ball: size 5, 0.43 kg, 220 mm diameter

```csv
case,wheel1,wheel2,wheel3,launch_mps,spin_rps,range_m,lateral_m,peak_m,time_s,current_risk
straight_pass,2604,2604,2604,13.2,0.0,7.2,0.0,0.61,0.58,MEDIUM: watch BMS / branch current
light_curve_assist,2604,2854,2354,13.2,3.67,8.1,0.32,0.72,0.66,MEDIUM: watch BMS / branch current
standard_curve_assist,2865,3000,2415,13.99,4.29,9.8,0.51,0.91,0.77,MEDIUM: watch BMS / branch current
```

## Interpretation

- `straight_pass` is the low-risk baseline preset.
- `light_curve_assist` uses moderate RPM differential and should be the first curve-ball field test.
- `standard_curve_assist` has higher RPM spread and should be tested only after straight/light presets are stable.

## Engineering cautions

- This is a screening model; real launch speed will depend strongly on wheel material, preload, contact time, and ball condition.
- Do not use these values for high-speed firing before protective cover and e-stop validation.
- Validate current draw with no ball first, then with low preload, then with real ball.

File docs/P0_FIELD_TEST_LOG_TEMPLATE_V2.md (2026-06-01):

# P0 现场测试记录表 v2（含环境字段）

## 基本信息
- 日期：
- 地点：
- 样机编号：
- 操作员：
- 记录员：
- 安全观察员：

## 环境信息
- 温度（°C）：
- 相对湿度（%）：
- 风速（m/s）：
- 风向：无风 / 顺风 / 逆风 / 左侧风 / 右侧风
- 地面：草地 / 人造草 / 塑胶
- 备注：

## 样机配置
### 机械配置
- 轮径：
- 轮宽：
- 轮面材料：
- 轮面硬度：
- 三轮预压：
  - wheel1：
  - wheel2：
  - wheel3：
- 导向筒：无 / 150mm / 200mm / 250mm
- 导向筒内径：

### 电控配置
- 电机：
- 节点板：
- 上位：
- 电源：
- 当前限流配置：
- 当前 ramp：

## 测试前检查
| 项目 | 结果 | 备注 |
|---|---|---|
| 主开关正常 | □通过 / □异常 |  |
| 急停正常 | □通过 / □异常 |  |
| 3 个 Node 在线 | □通过 / □异常 |  |
| wheel1/2/3 映射正确 | □通过 / □异常 |  |
| 无故障码 | □通过 / □异常 |  |
| 防护罩正常 | □通过 / □异常 |  |
| 场地清空 | □通过 / □异常 |  |

## 测试项目记录
| 序号 | 环境集 | 导向筒 | preset | wheel1 target/actual | wheel2 target/actual | wheel3 target/actual | 球速 | 横向偏移 | 落点偏差 | 打滑 | 旋转削弱 | 备注 |
|---|---|---|---|---|---|---|---|---|---|---|---|---|
| 1 |  |  |  |  |  |  |  |  |  |  |  |  |
| 2 |  |  |  |  |  |  |  |  |  |  |  |  |
| 3 |  |  |  |  |  |  |  |  |  |  |  |  |
| 4 |  |  |  |  |  |  |  |  |  |  |  |  |
| 5 |  |  |  |  |  |  |  |  |  |  |  |  |
| 6 |  |  |  |  |  |  |  |  |  |  |  |  |

## 模式汇总
### 直传（straight_pass）
- 最稳定导向方案：
- 最佳环境：
- 球速范围：
- 偏航情况：
- 落点误差：

### 轻弧线（light_left/right_curve）
- 最稳定导向方案：
- 最佳环境：
- 横向偏移：
- 旋转可辨识度：
- 落点误差：

### 标准弧线（standard_left/right_curve）
- 最稳定导向方案：
- 最佳环境：
- 横向偏移：
- 旋转可辨识度：
- 落点误差：

## 故障 / 异常记录
| 编号 | 现象 | preset | 导向筒 | 环境 | 初步原因 | 是否复现 |
|---|---|---|---|---|---|---|
| 1 |  |  |  |  |  |  |
| 2 |  |  |  |  |  |  |
| 3 |  |  |  |  |  |  |

## 安全检查
| 项目 | 结果 | 备注 |
|---|---|---|
| 急停有效 | □通过 / □异常 |  |
| 连续发射无明显过热 | □通过 / □异常 |  |
| 无结构松动 | □通过 / □异常 |  |
| 导向筒无明显摩擦痕迹 | □通过 / □异常 |  |
| 防护罩无干涉 | □通过 / □异常 |  |

## 今日结论
### 当前最佳组合
- 环境：
- 导向筒：
- preset：
- 球速：
- 落点稳定性：
- 弧线稳定性：

### 当前最大问题
1. 
2. 
3. 

### 下一轮建议
1. 
2. 
3.

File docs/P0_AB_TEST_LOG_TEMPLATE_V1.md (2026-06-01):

# P0 A/B 测试记录模板 v1

## 基本信息
- 日期：
- 测试人：
- 样机编号：
- 地点：

## 当前配置
- 轮径：
- 轮宽：
- 轮面材料/硬度：
- 三轮预压：
- 导向筒：无 / 150 / 200 / 250
- 导向筒内径：
- preset：

## 记录项
- wheel1 target/actual：
- wheel2 target/actual：
- wheel3 target/actual：
- 球速：
- 横向偏移：
- 落点偏差：
- 旋转方向是否清晰：
- 是否打滑：
- 是否削弱旋转：
- 主观结论：

## 结论
- 是否保留当前导向筒长度：
- 与无导向相比是否更稳定：
- 下一轮建议：

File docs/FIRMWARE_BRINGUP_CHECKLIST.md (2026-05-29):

# 固件 Bring-up Checklist v1

## Host
- [ ] 可下载
- [ ] 串口日志正常
- [ ] CAN 初始化正常
- [ ] 传感器输入可读
- [ ] 急停输入可读

## Single Motor Node
- [ ] 可下载
- [ ] 3.3V/VBUS 采样正常
- [ ] Driver fault 可读
- [ ] Hall 读数正常
- [ ] PWM 输出正常
- [ ] 单电机低速开环正常
- [ ] 单电机速度闭环正常

## Host + Single Node
- [ ] `SET_RPM` 生效
- [ ] `STATUS` 回传正常
- [ ] `HEARTBEAT` 正常
- [ ] 通信超时保护正常

## 3 Nodes
- [ ] 三节点可同时在线
- [ ] 三轮同步启动正常
- [ ] 轮间偏差在目标范围内

## Feed / Launch
- [ ] 管道有球检测正常
- [ ] 发射位到球检测正常
- [ ] 出球检测正常
- [ ] 单球分离逻辑正常
- [ ] 状态机完整跑通

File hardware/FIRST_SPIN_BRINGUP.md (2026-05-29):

# 首版打样与上电 Bring-up 注意事项 v1

## 1. 打样前检查
- ERC / DRC 全绿
- 电源极性、端子方向二次确认
- CAN、Hall、Motor 接口丝印方向明确
- 急停硬切回路确认
- 高低压 / 功率 / 逻辑区丝印区分清楚

## 2. 首次上电顺序
### Host 板
1. 不插传感器、不插执行器
2. 仅上 24V，确认 5V/3.3V 正常
3. 烧录最小固件
4. 检查 UART / CAN 初始化

### Motor Node 板
1. 不接电机，先上电
2. 测 3.3V / VDRV / Driver enable 默认态
3. 检查 MCU 下载与 SWD
4. 检查 Driver fault 是否正常
5. 再接 Hall，不接三相功率输出负载
6. 最后接电机，先低压/限流测试

## 3. 首轮限制
- 电源限流开启
- 不上球
- 先单节点
- 先低 RPM
- 先不开自动供球

## 4. 常见风险点
- Hall 线序错误
- 相线顺序错误
- CAN 终端重复或缺失
- Driver bootstrap / gate 阻值不合适
- Shunt 采样地回流污染 ADC
- 急停只做了软件没做硬切

## 5. 建议首轮验证清单
- Host 供电正常
- Host 串口日志正常
- CAN 通信正常
- Node 下载正常
- Driver 无故障上电
- Hall 读数正常
- 单电机低速闭环正常
- 急停能硬切使能

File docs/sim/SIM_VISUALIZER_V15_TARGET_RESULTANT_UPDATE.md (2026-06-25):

# SIM_VISUALIZER_V15_TARGET_RESULTANT_UPDATE

## Owner 修正
本轮口径变更：

- 合力方向直接向目标方向发射
- A/B/C 三电机差速用于产生侧旋和弧线
- 差速不能把初始瞄准方向带偏
- 初始合力矢量必须对准目标方向

---

## Widget 更新
Widget：`仿真验证交互可视化`

版本：v15

文件：
- `widgets/sim-visualizer.html`

---

## 主要改动

### 1. 合力方向锁定目标方向
原 v14/v13 里合力方向会受 A/C 差速影响发生水平偏转。  
现在修正为：

```text
force_heading = target_heading
```

即：
- `目标方向` 控制初始瞄准方位
- A/B/C 差速只进入侧旋模型
- 不再用差速改写初始发射方向

### 2. 侧旋与瞄准解耦
新口径：

| 项 | 作用 |
|---|---|
| 目标方向 | 决定初始合力瞄准方向 |
| 三电机倾斜角 | 决定向上发射角 |
| A/B/C 差速 | 决定足球飞行中的侧旋 / 弧线 |
| friction / preload | 决定能量传递和打滑风险 |

### 3. 合力图文案修正
合力矢量分解图中：

- A/B/C 不再显示为“改变合力瞄准”
- 改为“侧旋加速 / 侧旋释放”
- 橙色合力箭头表示直接指向目标方向

---

## CAD v1.2f
新增：

- `cad/assembly/p0-single-ball-launcher-v3/outrunner_target_resultant_tube_v1_2f.scad`

相对 v1.2e：
- 保留照片口径：中心短管 + 三电机周向嵌入
- 保留 roll 90° + 倾斜发射
- 新增 `target_resultant_locked = true`
- 注释明确：初始合力方向 = 目标方向；差速只用于侧旋/弧线

---

## 当前结论
v15 主线口径：

**目标方向锁定初始合力 → 三电机倾斜嵌入直接发射 → A/B/C 差速只负责比赛弧线。**

下一步继续：

1. 加目标点/门框/人墙参照
2. 加侧旋落点云
3. 加不可控热区
4. 加 A/B/C 独立压紧校准输入

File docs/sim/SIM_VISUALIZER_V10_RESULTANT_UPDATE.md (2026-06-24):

# SIM_VISUALIZER_V10_RESULTANT_UPDATE

## Owner 修正
本轮口径变更：

- 去除保护罩表达
- 突出 3 个外转子电机嵌入发射管
- 发射出球方向 = **三电机共同作用合力方向**
- 圆管出口不再单独定义最终出球方向，只保留为短导向/结构基准

---

## Widget 更新
Widget：`仿真验证交互可视化`

版本：v10

文件：
- `widgets/sim-visualizer.html`

---

## 主要改动

### 1. 发射方向逻辑改为合力方向
新增合力方向估算：

```text
force_heading = manual_trim + f(A rpm, B rpm, C rpm)
```

当前简化规则：

- A/C 差速给左右方向分量
- B 参与稳定和复合侧旋修正
- `合力方向微调` 只作为总装调试偏置

### 2. 3D 箭头跟随合力方向
原来箭头固定按短管出口方向显示。  
现在随 A/B/C RPM 分配变化：

- 左弧：合力方向偏左
- 右弧：合力方向偏右
- 复合弧线：合力方向 + 侧旋轨迹共同显示

### 3. 去除保护罩口径
文案和提示已从“防护罩避让”改为：

- 无保护罩
- 短发射管出口后开放避让
- 重点看三电机嵌入发射管和出球合力方向

### 4. CAD 可视基准新增 v1.2b
新增：

- `cad/assembly/p0-single-ball-launcher-v3/outrunner_embedded_short_tube_v1_2b.scad`

v1.2b 基于 v1.2a，但：

- `show_shield_tabs = false`
- 注释改为三电机合力方向出球
- 圆管轴线保留为结构基准，不再作为唯一出球方向

---

## 当前结论
v10 之后仿真主线改为：

**无保护罩 + 三电机嵌入短发射管 + 三电机合力方向出球 + 侧旋轨迹族。**

下一步继续：

1. 进一步强化 3D 中电机嵌入发射管的截面表达
2. 加 A/B/C 合力矢量分解图
3. 加落点云 / 不可控区间热区
4. 把实测回填映射到 A/B/C 三点校准

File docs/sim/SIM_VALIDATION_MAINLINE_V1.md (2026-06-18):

# SIM_VALIDATION_MAINLINE_V1

## 定位
从现在开始，`v1.2` 阶段以 **仿真验证** 作为主线推进，机械验证与结构修正围绕仿真结论服务。

当前口径不是继续发散几何，而是先把下面这条链条跑顺：

```text
几何冻结参数 -> 仿真输入 -> RPM / preload / friction 窗口 -> 实测回填 -> 再修结构
```

---

## 主线目标
在当前 6354 / 三工位 / 232 内径 / 可调压紧的冻结约束下，优先回答 4 个问题：

1. 当前方案的 **安全起转窗口** 是多少
2. 哪组 `RPM / preload / friction` 组合适合作为首轮实测
3. 哪些参数对出球速度 / 弧线 / 射程最敏感
4. 哪些机械变量必须回填到仿真里，否则继续做结构会失真

---

## 当前仿真基础
当前仓库已具备：
- `sim/football_launch_model.py`
- `sim/optimization_sweep_v1.py`
- `sim/params_p0.yaml`
- `sim/results_p0.md`
- `docs/sim/P0_SIM_RECOMMENDATIONS_V2.md`

当前模型可用于筛选：
- wheel RPM 组合
- preload 对耦合效率的影响
- friction 对出球速度的影响
- spin bias 对弧线的影响
- ramp 时间对电流风险的粗筛

---

## 这轮主线结论

### 1. 仿真验证应先于进一步结构发散
原因很直接：
- 当前机械主线已经冻结到 `v1.1 / v1.2`
- 但 `preload`、`rubber`、`friction`、`actual exit speed` 还没有闭环
- 如果继续画结构而不先把这些变量收口，后面很容易出现“结构按错目标优化”

所以当前主线应改成：
**先用仿真把实测窗口和参数敏感度锁出来，再决定结构只改哪些点。**

### 2. 当前模型里，摩擦系数和预压量是第一批主敏感参数
基于 `sim/football_launch_model.py` 的批量筛选结果：

#### straight_validation
- 发射速度范围：`9.83 ~ 14.10 m/s`
- 射程范围：`4.6 ~ 8.0 m`

#### light_curve_validation
- 发射速度范围：`9.83 ~ 14.10 m/s`
- 射程范围：`5.0 ~ 9.0 m`
- 横向偏移范围：`0.17 ~ 0.38 m`

#### standard_curve_validation
- 发射速度范围：`10.42 ~ 14.94 m/s`
- 射程范围：`6.0 ~ 10.9 m`
- 横向偏移范围：`0.25 ~ 0.60 m`

这说明在当前模型里：
- `friction_coeff`
- `preload_mm`
- `spin_bias_rpm`

会直接决定首轮实测是否落在可控窗口。

### 3. 仿真先行时，首轮实测不该一上来追大弧线
建议先按这条顺序：
1. `straight_validation`
2. `light_curve_validation`
3. `standard_curve_validation`

也就是：
- 先验证直球速度是否能闭环
- 再验证轻弧线是否稳定
- 最后再上标准弧线

这比先冲高 preload / 高 spin bias 更稳。

---

## 当前推荐的仿真主线测试窗口

### A. 首轮安全窗口
作为第一轮实测起点，优先用：
- `RPM_CAP = 3000`
- `ramp = 5s`
- `preload = 8 ~ 10 mm`
- `friction_coeff` 按 `0.55 ~ 0.65` 作为初始估计

目的：
- 先证明系统可重复发球
- 先拿到 exit speed / current / wheel slip 的一批数据
- 避免过早被高压紧、高摩擦带偏

### B. 弧线测试窗口
当直球闭环后，再进：
- `spin_bias_rpm = 250` 做轻弧线
- `spin_bias_rpm = 450` 做标准弧线
- `ramp = 6s` 用于更保守的高差速验证

### C. 当前不建议直接当默认值的组合
不建议一开始默认：
- 高 preload
- 高包胶厚度
- 高 spin bias

原因：
这些组合会把机械不确定性、动平衡风险和电流风险叠在一起，失去排障顺序。

---

## 与机械验证的接口关系
仿真主线不替代机械验证，但会重新排序：

### 机械验证继续保留
仍然要做：
- 6354 实测外径 / 长度 / 端面孔距
- 包胶厚度与压紧量联动
- 包胶后动平衡
- 防护罩散热 / 装配 / 维护空间
- 工具进入空间

### 但推进顺序改成
1. **先把仿真输入边界锁出来**
2. **再让机械验证去填这些输入**
3. **最后只修正真正影响仿真结果的结构变量**

换句话说：
机械验证不再平均推进，而是优先服务仿真回填。

---

## 当前新增输出
这轮新增：
- `docs/sim/SIM_VALIDATION_MAINLINE_V1.md`
- `docs/sim/SIM_SENSITIVITY_MATRIX_V1.csv`

其中 `SIM_SENSITIVITY_MATRIX_V1.csv` 用于记录：
- `friction_coeff`
- `preload_mm`
- `launch_mps`
- `range_m`
- `lateral_m`
- `current_risk`

便于后面把实测数据一项项回填对比。

---

## 下一步
接下来主线继续补两块：

1. **仿真实测回填模板**
   - 把 radar / slow-motion / current log / wheel rpm 实测值接到 sim 输出上

2. **仿真参数冻结表**
   - 明确哪些参数现在允许调，哪些参数必须冻结，不让现场测试时乱漂

---

## 结论
当前阶段，主线正式切到：

**仿真验证优先，机械验证围绕仿真输入与实测回填服务。**

后续结构修正只处理两类问题：
1. 影响仿真输入边界的
2. 被实测证明会导致仿真失真的

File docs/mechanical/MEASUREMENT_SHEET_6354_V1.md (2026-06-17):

# MEASUREMENT_SHEET_6354_V1

## 用途
用于 `v1.2` 工程验证阶段锁定 6354 实物接口，不再靠占位参数推进关键孔位和窗口边界。

适用对象：
- 6354 外转子样件
- 端面固定板 / 槽孔模板
- 发射筒窗口与防护罩接口校核

---

## 样件信息
| 字段 | 记录 |
|---|---|
| 电机品牌/型号 |  |
| 批次/供应商 |  |
| 样件编号 |  |
| 测量日期 |  |
| 测量人 |  |
| 测量工具 | 游标卡尺 / 千分尺 / 深度尺 |

---

## 核心尺寸记录表

### A. 外壳包络
| 项目 | 符号 | 设计占位 | 实测值 | 偏差 | 备注 |
|---|---|---:|---:|---:|---|
| 外壳直径 | `motor_d` | 63.0 mm |  |  | |
| 外壳长度 | `motor_len` | 54.0 mm |  |  | |
| 前端盖外径 |  |  |  |  | |
| 后端盖外径 |  |  |  |  | |
| 工作带有效宽度 |  |  |  |  | |

### B. 端面安装接口
| 项目 | 符号 | 设计占位 | 实测值 | 偏差 | 备注 |
|---|---|---:|---:|---:|---|
| 中心凸台/轴承座直径 | `end_face_center_hole_d` | 24.0 mm |  |  | |
| 孔数 |  | 待测 |  |  | |
| 孔径 | `mount_hole_d` | 5.5 mm clearance |  |  | |
| X 向孔距 | `mount_hole_x_spacing` | 30.0 mm |  |  | |
| Z 向孔距 | `mount_hole_z_spacing` | 30.0 mm |  |  | |
| 可用牙深 |  | 待测 |  |  | |
| 螺纹规格 |  | 待测 |  |  | |

### C. 装配与工具空间
| 项目 | 目标 | 实测/观察 | 是否通过 | 备注 |
|---|---|---|---|---|
| 端面螺钉可正常上紧 | 可装配 |  |  | |
| 工具可进入 | 可维护 |  |  | |
| 与桥接件无干涉 | 可并线 |  |  | |
| 与护罩耳位无干涉 | 可防护 |  |  | |

---

## 判定规则
### 直接通过
满足以下全部条件时，可直接回填 CAD：
1. 外壳直径 / 长度偏差在可接受范围内
2. 端面孔距落在当前槽孔补偿范围内
3. 中心凸台与中心避让孔不冲突
4. 螺钉与工具进入空间成立

### 进入 `v1.1a` 定点修正
满足任一条件则进入 `v1.1a`：
- 孔距超出当前槽孔补偿
- 外壳长度导致窗口长度不足
- 外壳直径导致窗口边界或护罩孔位风险上升
- 端面凸台直径与现中心避让冲突

---

## CAD 回填项
实测完成后，至少同步这些参数：
```scad
motor_d
motor_len
end_face_center_hole_d
mount_hole_x_spacing
mount_hole_z_spacing
mount_slot_extra
```

---

## 备注
当前版本只锁接口，不在这里做新结构发散。若实测与冻结主线冲突，只允许：
- 更新参数
- 调整槽孔/耳位/局部窗口
- 回到 `v1.1a` 做定点修正

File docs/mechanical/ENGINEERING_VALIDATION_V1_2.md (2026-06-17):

# ENGINEERING_VALIDATION_V1_2

## 范围定义
`v1.2` 的目标不是开新方向，而是把当前冻结的 `v1.1` 方案整理成可验证、可制造、可改版的工程验证包。

当前冻结对象：
- `cad/assembly/p0-single-ball-launcher-v3/outrunner_launch_tube_v1_1.scad`
- `docs/mechanical/OUTRUNNER_LAUNCH_TUBE_V1_1.md`
- `docs/renders/OUTRUNNER_LAUNCH_TUBE_THREE_VIEW_V1_1.svg`

当前几何冻结前提：
- 6354 外转子
- 三电机中心线同平面
- 三工位等边三角形 / 120° 均布
- 3 外转子与球直接接触
- 底面固定优先
- 可调，但刚性优先
- 发射筒 `inner_d = 232`
- 默认压紧量 `2.5mm`，允许 `2–3mm` 微调

---

## 验证总表

| 验证项 | 目标 | 风险等级 | 当前状态 |
|---|---|---|---|
| 6354 实测外径 / 长度 / 端面孔距 | 锁定真实接口边界 | 高 | 待测 |
| 包胶厚度与压紧量联动 | 防止压紧量失控 | 高 | 待测 |
| 包胶后动平衡 | 防止高速振动失控 | 高 | 待测 |
| 透明防护罩散热 / 装配 / 维护空间 | 防止护罩可装不可用 | 中高 | 待测 |
| 端面固定板与外框工具进入空间 | 防止可设计不可装配 | 中 | 待测 |

---

## 1. 6354 实测外径 / 长度 / 端面孔距

### 验证目的
把当前参数占位改成实物边界，避免主模型、窗口尺寸、安装孔位、防护罩孔位全都建立在假设值上。

### 验证方法
1. 取目标 6354 电机实物样件
2. 测量并记录：
   - 外壳实测直径
   - 外壳实测长度
   - 端面孔数 / 孔径 / 孔距
   - 中心凸台 / 轴承座直径
   - 紧固件规格与可用牙深
3. 与当前 CAD 参数逐项对照：
   - `motor_d`
   - `motor_len`
   - `mount_hole_x_spacing`
   - `mount_hole_z_spacing`
   - `end_face_center_hole_d`
4. 回填到 CAD 顶部参数并复核窗口包络

### 通过标准
- 实测数据已形成表格并归档
- CAD 参数已同步更新
- 槽孔补偿量仍在可接受范围内
- 电机端面安装不会碰到窗口边缘、防护罩耳位、桥接件

### 风险等级
**高**

### 失败后的修改路径
- 若孔距偏差小：仅修正槽孔参数，形成 `v1.1a`
- 若外壳长度/直径偏差明显：同步修正窗口尺寸、接触带位置、护罩孔位，形成 `v1.1a`
- 若端面结构与当前桥接逻辑不兼容：回到主线固定件设计，更新 `MAINLINE_MODEL_ADJUSTMENT`

---

## 2. 包胶厚度与压紧量联动

### 验证目的
确认包胶后总外径变化不会把默认 `2.5mm` 压紧量推到不可控区间。

### 验证方法
1. 设定包胶厚度候选值：
   - `0mm`
   - `1.0mm`
   - `1.5mm`
   - `2.0mm`
2. 计算每种包胶后的等效外径
3. 对照当前发射筒 `inner_d = 232` 与电机中心位置，计算最终压紧量
4. 复核调节槽是否足以把压紧量拉回 `2–3mm`
5. 输出联动表：
   - 包胶厚度
   - 等效外径
   - 理论压紧量
   - 是否需要调节

### 通过标准
- 对所有计划采用的包胶厚度，最终压紧量都能控制在 `2–3mm`
- 不需要为了补偿包胶去引入大行程柔性调节
- 小行程调节即可完成装配校准

### 风险等级
**高**

### 失败后的修改路径
- 若包胶后压紧量 > `3mm`：
  - 优先减薄包胶
  - 次选微调电机中心位置 / 调节槽范围
  - 必要时修正窗口和安装基准，形成 `v1.1a`
- 若包胶后压紧量 < `2mm`：
  - 通过垫片 / 调节槽补偿
  - 必要时增大包胶厚度规格下限

---

## 3. 包胶后动平衡

### 验证目的
确认外转子壳体加胶层后仍能在目标转速区间安全运行，不引入不可接受振动。

### 验证方法
1. 明确目标转速区间
2. 制作至少一组包胶样件
3. 做静平衡初筛：
   - 观察重心偏移
   - 检查胶层厚度一致性
4. 做低速到目标转速的逐级测试：
   - 振动
   - 异响
   - 温升
   - 固定件松动趋势
5. 记录：
   - 最大稳定转速
   - 振动是否可接受
   - 是否需要二次修整/配重

### 通过标准
- 目标工作转速区间内无明显异常振动
- 固定件不松动
- 包胶不脱落、不偏磨
- 不需要依赖临时性补胶修振动

### 风险等级
**高**

### 失败后的修改路径
- 改包胶工艺：材料、厚度、公差、贴附方式
- 降低允许最高转速
- 增加动平衡工序
- 若风险不可控，回退到“外转子工作带可替换套件”方案，不改几何主线但改工艺件定义

---

## 4. 透明防护罩散热 / 装配 / 维护空间

### 验证目的
确保防护罩不是“纸面安全件”，而是真能装、能拆、能散热、能维护。

### 验证方法
1. 基于当前护罩耳位建立透明罩包络
2. 检查：
   - 旋转壳体包络与护罩净距
   - 螺钉头与工具进入空间
   - 上球 / 维护动作空间
   - 散热气流路径
3. 做一次装配顺序推演：
   - 先装电机还是先装护罩
   - 护罩拆装是否需要大面积拆结构
4. 若有样件，做一次纸板/亚克力快速样件验证

### 通过标准
- 护罩可独立拆装
- 不碰转子包络
- 螺钉可实际拧到
- 不明显堵死散热路径
- 不显著妨碍上球与维护

### 风险等级
**中高**

### 失败后的修改路径
- 优先调耳位和孔距，形成 `v1.1a`
- 必要时改护罩分片方式
- 仍不改变三窗口主几何和 6354 主线关系

---

## 5. 端面固定板与外框工具进入空间

### 验证目的
确认当前固定结构不是“能画不能装”，尤其是螺丝、内六角、套筒和手部操作空间。

### 验证方法
1. 标出以下装配动作：
   - 安装端面固定板
   - 安装/调整桥接件
   - 固定到底座或外框
   - 调节压紧量
2. 为每个动作检查：
   - 工具进入方向
   - 工具摆角空间
   - 手部操作净空
   - 是否被护罩 / 窗口 / 外框遮挡
3. 输出装配顺序建议

### 通过标准
- 关键紧固件都有明确工具路径
- 不需要拆掉大半结构才能做压紧量微调
- 外框、护罩、端面固定板之间不存在硬干涉

### 风险等级
**中**

### 失败后的修改路径
- 调整螺钉方向
- 调整桥接件宽度/位置
- 调整外框与固定板间距
- 必要时改工具孔或检修窗口

---

## 验证执行顺序
建议按这个顺序走，避免返工：

1. **先锁 6354 实测尺寸**
2. **再做包胶厚度与压紧量联动**
3. **再做动平衡验证**
4. **再做透明护罩装配/散热验证**
5. **最后做工具进入与装配顺序验证**

原因：
- 前两项决定基础几何边界
- 动平衡决定外转子工艺是否可行
- 护罩和工具空间都属于后续装配边界验证

---

## 输出要求
v1.2 阶段至少形成以下交付：
- `ENGINEERING_VALIDATION_V1_2.md`
- 6354 实测参数表
- 包胶厚度 / 压紧量联动表
- 动平衡测试记录
- 护罩与装配空间检查记录
- 工具进入与装配顺序说明

---

## 阶段结论口径
只有在以下条件同时满足时，才允许从 `v1.2` 进入下一阶段：
- 关键实测参数已锁
- 压紧量可控
- 包胶后可稳定运行
- 护罩可装可拆可维护
- 工具进入与装配顺序成立

否则，只允许回到：
- `v1.1a` 做定点修正
- 或更新主线固定/接口设计

不允许在 `v1.2` 阶段发散成新方向。

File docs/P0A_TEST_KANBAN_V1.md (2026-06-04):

# P0-A 测试看板 v1

## 当前目标

从采购到低速单球射出，形成最小闭环。

## 状态栏

### TODO

| ID | 任务 | 负责人 | 阻塞 |
|---|---|---|---|
| P0A-01 | P0-A 物料下单 | owner / PM | 采购确认 |
| P0A-02 | 台架电源与急停链路接线 | engineering | 物料到货 |
| P0A-03 | 单个 B-G431B-ESC1 上电 | engineering | 物料到货 |
| P0A-04 | 单电机 Hall 读取 | engineering | 电机到货 |
| P0A-05 | 单电机 500/1000/2000rpm | engineering | P0A-04 |
| P0A-06 | 三电机 CAN 通信 | engineering | P0A-03 |
| P0A-07 | 三轮同步空载 | engineering | P0A-05/P0A-06 |
| P0A-08 | 防护罩安装 | mechanical | PC 板到货 |
| P0A-09 | 急停硬切验证 | engineering | P0A-02 |
| P0A-10 | 低速单球 B1/B2/B3 | engineering | P0A-07/P0A-08/P0A-09 |
| P0A-11 | 轻弧线 C1 | engineering | P0A-10 稳定 |
| P0A-12 | 实测数据回填仿真 | PM / engineering | P0A-10/P0A-11 |

### DOING

| ID | 任务 | 备注 |
|---|---|---|
|  |  |  |

### DONE

| ID | 任务 | 证据 |
|---|---|---|
| DOC-01 | P0-A 仿真模型 | `sim/football_launch_model.py` |
| DOC-02 | P0-A 采购清单 | `docs/procurement/P0A_PURCHASE_CHECKLIST_V1.md` |
| DOC-03 | P0-A 测试记录表 | `docs/P0A_TEST_LOG_TEMPLATE_V1.md` |

## 升级条件

只有满足以下条件，才进入 P0-B 高电流/现场测试：

1. 三轮空载同步通过。
2. 急停硬切通过。
3. 低速单球出球稳定。
4. 电流峰值有记录。
5. 防护罩完整。
6. 仿真参数完成第一次回填。

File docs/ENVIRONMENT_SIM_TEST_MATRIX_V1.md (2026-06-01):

# 环境仿真测试矩阵 v1

## 目标
在不同环境条件下验证：
- 出球速度稳定性
- 直传轨迹稳定性
- 轻弧线/标准弧线可重复性
- 风对落点和横向偏移的影响

## 预设
- `P1`：straight_pass
- `P2`：light_left_curve
- `P3`：light_right_curve
- `P4`：standard_left_curve
- `P5`：standard_right_curve

## 最小测试矩阵
| Env | Wind | Preset | 目标 |
|---|---|---|---|
| E0 | W0 | P1 | 直传基线 |
| E0 | W0 | P4 | 标准左弧线基线 |
| E1 | W0 | P1 | 常规训练直传 |
| E1 | W0 | P4 | 常规训练标准左弧线 |
| E1 | W3 | P4 | 侧风下标准左弧线 |
| E1 | W4 | P5 | 侧风下标准右弧线 |
| E2 | W0 | P1 | 低温不利环境直传 |
| E2 | W0 | P4 | 低温不利环境标准左弧线 |
| E2 | W3 | P4 | 低温 + 侧风下标准左弧线 |

## 记录项
- 环境：温度 / 湿度 / 风速 / 风向
- preset
- wheel1/2/3 target/actual
- 球速
- 横向偏移
- 落点误差
- 旋转是否清晰
- 是否打滑

## 判定重点
1. 温度变化是否明显影响球速
2. 湿度变化是否增加打滑
3. 侧风是否放大/削弱设备弧线
4. 落点偏差是否仍可记录、可调参

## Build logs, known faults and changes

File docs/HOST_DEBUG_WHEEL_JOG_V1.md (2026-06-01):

# Host 单轮点动调试命令 v1

## 新增能力
在 Host 调试命令里增加单独 wheel 点动/覆盖目标 rpm：
- `jog wheel1 800`
- `jog wheel2 800`
- `jog wheel3 800`
- `jog off`

## 用途
1. 校验 wheel1/2/3 与物理轮位映射
2. 单独检查某一路 node 是否正常响应
3. 不经过 spinMode/mixer，直接给单轮目标 rpm
4. bring-up 时更快定位 wiring / nodeId / node fault

## 当前实现
- `host_state` 新增 `debugOverride`
- `debug_command.cpp` 新增 `jog wheel1/2/3` 与 `jog off`
- `can_host_loop.cpp` 在 debugOverride 打开时直接使用单轮目标 rpm

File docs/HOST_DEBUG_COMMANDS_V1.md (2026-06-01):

# Host 调试命令接口 v1

## 文件
- `firmware/host-esp32s3/src/debug_command.h`
- `firmware/host-esp32s3/src/debug_command.cpp`

## 目标
提供一个最小文本命令接口骨架，方便现场调试时手动改参数、触发发射、触发急停、清故障。

## 当前支持命令
- `set base 2100`
- `set delta 250`
- `spin straight`
- `spin topspin`
- `spin backspin`
- `spin left`
- `spin right`
- `fire`
- `estop`
- `clear fault`
- `ball loaded`
- `ball empty`

## 当前用途
- bring-up 阶段手动调 `baseRpm`
- 快速切换 `spinMode`
- 手动触发 `FIRE`
- 验证急停/故障恢复流程

## 下一步
- 接到串口命令行
- 接到 WebSerial / 上位机调试面板
- 增加单独 wheel 点动命令

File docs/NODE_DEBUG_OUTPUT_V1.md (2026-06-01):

# Node 日志输出骨架 v1

## 文件
- `firmware/node-bg431b-esc1/include/node_debug.h`
- `firmware/node-bg431b-esc1/src/node_debug.cpp`

## 当前输出
### BOOT
输出：
- 板卡名
- wheel 名称
- nodeId
- 电机方向
- Hall 极性

### STATUS
输出：
- nodeId
- state
- enabled
- targetRpm
- actualRpm
- busVoltage
- phaseCurrent
- temp
- faultCode

### FAULT
输出：
- nodeId
- state
- faultCode
- actualRpm
- current
- temp

## 目的
- 方便单板 bring-up
- 方便核对 wheel1/2/3 实例映射
- 方便快速判断是通信问题、控制问题还是硬件 fault

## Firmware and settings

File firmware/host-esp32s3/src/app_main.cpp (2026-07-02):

#include "app_config.h"
#include "hal/host_hal.h"
#include "debug_command.h"
#include "host_state.h"
#include <stdio.h>

extern void host_can_control_tick(void);
extern void host_can_poll_rx(void);
extern void launch_state_machine_step(void);
extern void telemetry_publish(void);

extern "C" void app_entry() {
  HostState* s = host_state_get();
  printf("%s boot\n", HOST_FIRMWARE_NAME);

  host_hal_init();
  host_hal_can_init();

  s->cmd.baseRpm = 2100;
  host_debug_apply_text_command("ball loaded");
  s->cmd.deltaRpm = 250;
  s->cmd.spinMode = STRAIGHT;
  s->cmd.fireRequest = 0;
  s->stateEnterMs = host_hal_millis();

  while (1) {
    s->cmd.estop = (uint8_t)host_hal_estop_active();
    s->sensors.ballLoaded = (uint8_t)host_hal_sensor_ball_loaded();
    host_can_poll_rx();
    launch_state_machine_step();
    host_can_control_tick();
    telemetry_publish();
  }
}

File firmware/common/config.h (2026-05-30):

#pragma once

#define RPM_MIN 500
#define RPM_MAX 3000
#define P0_TARGET_SPEED_MIN_MS 14
#define P0_TARGET_SPEED_MAX_MS 18
#define NODE_STATUS_PERIOD_MS 20
#define HOST_CONTROL_PERIOD_MS 20
#define COMMS_TIMEOUT_MS 200
#define FEED_TO_CHAMBER_TIMEOUT_MS 1500
#define FIRE_TO_EXIT_TIMEOUT_MS 1000
#define RELOAD_DELAY_MS 300

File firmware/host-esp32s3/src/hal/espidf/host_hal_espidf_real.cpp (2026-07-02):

// ESP-IDF real HAL implementation for Host (ESP32-S3)
// Replaces host_hal_stub.cpp when targeting real hardware.
//
// Pin assignments — adjust to match final PCB:
//   TWAI_TX = GPIO 5, TWAI_RX = GPIO 4
//   SENSOR_BALL_LOADED = GPIO 6, SENSOR_TUBE_BALL = GPIO 7
//   SENSOR_CHAMBER = GPIO 15, SENSOR_EXIT = GPIO 16
//   ESTOP_IN = GPIO 17, LAUNCH_TRIGGER = GPIO 18
//   FEED_ACTUATOR = GPIO 8, STATUS_LED = GPIO 48, BUZZER = GPIO 47

#include "host_hal.h"
#include "driver/twai.h"
#include "driver/gpio.h"
#include "esp_timer.h"
#include <stdio.h>
#include <string.h>

// --- Pin definitions ---
#define PIN_TWAI_TX         GPIO_NUM_5
#define PIN_TWAI_RX         GPIO_NUM_4
#define PIN_SENSOR_BALL     GPIO_NUM_6
#define PIN_SENSOR_TUBE     GPIO_NUM_7
#define PIN_SENSOR_CHAMBER  GPIO_NUM_15
#define PIN_SENSOR_EXIT     GPIO_NUM_16
#define PIN_ESTOP           GPIO_NUM_17
#define PIN_LAUNCH          GPIO_NUM_18
#define PIN_FEED_ACTUATOR   GPIO_NUM_8
#define PIN_STATUS_LED      GPIO_NUM_48
#define PIN_BUZZER          GPIO_NUM_47

// --- Millisecond timer ---
static volatile uint32_t g_millis = 0;

static void millis_timer_cb(void* arg) {
    (void)arg;
    g_millis++;
}

static esp_timer_handle_t g_millis_timer;

// ============================================================
// HAL interface implementation
// ============================================================

void host_hal_init(void) {
    // Sensor inputs (active-low, pull-up)
    gpio_config_t in_conf = {
        .pin_bit_mask = (1ULL << PIN_SENSOR_BALL) |
                        (1ULL << PIN_SENSOR_TUBE) |
                        (1ULL << PIN_SENSOR_CHAMBER) |
                        (1ULL << PIN_SENSOR_EXIT) |
                        (1ULL << PIN_ESTOP),
        .mode = GPIO_MODE_INPUT,
        .pull_up_en = GPIO_PULLUP_ENABLE,
        .pull_down_en = GPIO_PULLDOWN_DISABLE,
        .intr_type = GPIO_INTR_DISABLE,
    };
    gpio_config(&in_conf);

    // Outputs
    gpio_config_t out_conf = {
        .pin_bit_mask = (1ULL << PIN_LAUNCH) |
                        (1ULL << PIN_FEED_ACTUATOR) |
                        (1ULL << PIN_STATUS_LED) |
                        (1ULL << PIN_BUZZER),
        .mode = GPIO_MODE_OUTPUT,
        .pull_up_en = GPIO_PULLUP_DISABLE,
        .pull_down_en = GPIO_PULLDOWN_ENABLE,
        .intr_type = GPIO_INTR_DISABLE,
    };
    gpio_config(&out_conf);
    gpio_set_level(PIN_LAUNCH, 0);
    gpio_set_level(PIN_FEED_ACTUATOR, 0);
    gpio_set_level(PIN_STATUS_LED, 0);
    gpio_set_level(PIN_BUZZER, 0);

    // 1ms tick timer
    esp_timer_create_args_t timer_args = {
        .callback = millis_timer_cb,
        .name = "millis",
    };
    esp_timer_create(&timer_args, &g_millis_timer);
    esp_timer_start_periodic(g_millis_timer, 1000);

    printf("[host_hal] init complete\n");
}

void host_hal_delay_ms(uint32_t ms) {
    vTaskDelay(pdMS_TO_TICKS(ms));
}

uint32_t host_hal_millis(void) {
    return g_millis;
}

// --- CAN (TWAI 500kbps) ---

int host_hal_can_init(void) {
    twai_general_config_t g_config = TWAI_GENERAL_CONFIG_DEFAULT(
        (gpio_num_t)PIN_TWAI_TX, (gpio_num_t)PIN_TWAI_RX, TWAI_MODE_NORMAL);
    twai_timing_config_t t_config = TWAI_TIMING_CONFIG_500KBITS();
    twai_filter_config_t f_config = TWAI_FILTER_CONFIG_ACCEPT_ALL();

    if (twai_driver_install(&g_config, &t_config, &f_config) != ESP_OK) {
        printf("[host_hal] TWAI install failed\n");
        return -1;
    }
    if (twai_start() != ESP_OK) {
        printf("[host_hal] TWAI start failed\n");
        return -1;
    }
    printf("[host_hal] CAN 500kbps ready\n");
    return 0;
}

int host_hal_can_send(const HostCanFrame* frame) {
    twai_message_t msg = {
        .identifier = frame->canId,
        .data_length_code = frame->dlc,
    };
    memcpy(msg.data, frame->data, frame->dlc);
    return (twai_transmit(&msg, pdMS_TO_TICKS(5)) == ESP_OK) ? 0 : -1;
}

int host_hal_can_recv(HostCanFrame* frame) {
    twai_message_t msg;
    if (twai_receive(&msg, 0) != ESP_OK) return -1;
    frame->canId = (uint16_t)msg.identifier;
    frame->dlc = msg.data_length_code;
    memcpy(frame->data, msg.data, msg.data_length_code);
    return 0;
}

// --- Sensor reads ---

int host_hal_sensor_ball_loaded(void) {
    return (int)gpio_get_level(PIN_SENSOR_BALL);
}

int host_hal_sensor_tube_ball_present(void) {
    return (int)gpio_get_level(PIN_SENSOR_TUBE);
}

int host_hal_sensor_chamber_ready(void) {
    return (int)gpio_get_level(PIN_SENSOR_CHAMBER);
}

int host_hal_sensor_exit_detected(void) {
    return (int)gpio_get_level(PIN_SENSOR_EXIT);
}

int host_hal_estop_active(void) {
    return (int)gpio_get_level(PIN_ESTOP);
}

// --- Actuators ---

void host_hal_trigger_launch(void) {
    gpio_set_level(PIN_LAUNCH, 1);
    vTaskDelay(pdMS_TO_TICKS(50));
    gpio_set_level(PIN_LAUNCH, 0);
}

void host_hal_feed_request(void) {
    gpio_set_level(PIN_FEED_ACTUATOR, 1);
    vTaskDelay(pdMS_TO_TICKS(100));
    gpio_set_level(PIN_FEED_ACTUATOR, 0);
}

void host_hal_set_status_led(int on) {
    gpio_set_level(PIN_STATUS_LED, on ? 1 : 0);
}

void host_hal_set_buzzer(int on) {
    gpio_set_level(PIN_BUZZER, on ? 1 : 0);
}

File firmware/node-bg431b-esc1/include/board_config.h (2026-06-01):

#pragma once

#define NODE_BOARD_NAME "B-G431B-ESC1"
#define NODE_DEFAULT_ID 0x11
#define NODE_RPM_MIN 500
#define NODE_RPM_MAX 3000
#define NODE_CURRENT_LIMIT_CONT_A 20
#define NODE_CURRENT_LIMIT_PEAK_A 35
#define NODE_TEMP_LIMIT_C 85
#define NODE_STATUS_PERIOD_MS 20
#define NODE_HEARTBEAT_PERIOD_MS 100

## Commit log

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2026-06-01 Add practical curve pass presets and short guide tube draft
2026-06-01 Add short guide tube A/B test matrix and log template
2026-06-02 Add short guide tube 3D print draft
    [short_guide_tube_v1.scad]
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2026-06-04 Align P0 scope and replaceable wheel module
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2026-06-15 prioritize motor fixation and stiffness for 6354 mainline
    [p0_single_ball_launcher_outer_rotor_parametric_v10.scad]
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2026-06-19 fix 3d motor layout to ring-wrap mounting
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2026-06-22 integrate embedded short tube v1.2a baseline
    [outrunner_embedded_short_tube_v1_2a.scad]
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2026-06-26 model external rotor screw fixing v1.2n
    [outrunner_external_rotor_screw_fixed_v1_2n.scad]
2026-06-26 add tri-motor 6374 3D printed parts v1: 120° layout, 6 STL parts
    - frame_main: main frame with 3 motor mount bosses at 120°
    - motor_mount:法兰夹持 6374 电机
    - roller_wheel: V槽发射滚轮
    - structural_arm: 框架↔电机座连接臂
    - connector_flange: 两半框架法兰连接环
    - motor_side_plate: 侧盖板增加刚性
    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
    [connector_flange.stl, frame_main.stl, motor_mount.stl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]
2026-06-26 upgrade to manifold3d CSG: proper boolean ops for print-ready STL
    - motor_mount: M4 holes + M5 clamp hole + shaft bore (CSG subtracted)
    - frame_main: 120° hub bosses with M5 bolt holes + stiffening ring
    - roller_wheel: V-groove + keyway + set screw hole + lightening holes
    - structural_arm: M5 mounting holes + recess pocket + corner chamfers
    - connector_flange: 8x M5 bolt holes + 2x dowel pin holes
    - motor_side_plate: center ball bore + 3x motor pass-through + 3x mounting groups
    All parts now have proper through-holes and accurate geometry for FDM printing.
    [connector_flange.stl, frame_main.stl, motor_mount.stl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]
2026-06-26 redesign: independent 3-motor 120° from scratch
    6 parts, all with proper CSG boolean holes for direct FDM printing:
    - launch_tube: 320mm OD split tube, 120° motor bosses, M5 bolt holes
    - motor_mount: half-clamp for 6374, M4 motor holes, M5 side bolts
    - motor_arm: structural link with M5 holes, recess pocket, chamfers
    - launch_roller: 70mm crowned roller, V-groove, keyway, set screw
    - side_plate: end plate with ball bore, arm notches, lightening holes
    - flange_ring: tube joining ring with 8x M5 + dowel pins
    Ball: 220mm | Channel: 226mm ID | Motor center: 145mm from axis
    [connector_ring.stl, flange_ring.stl, frame_half.stl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]
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2026-06-27 monocoque redesign: integrated 3-motor shell (reference orange part)
    - monocoque_shell: single-piece body with 3 motor cradles at 120°,
    bridge ribs, wire slots, tube clamp, flange faces
    - motor_clamp_cap: arc clamp cap for each motor, M4 bolt holes
    - side_plate: end plate with ball bore + motor pass-throughs
    - flange_ring: tube joining ring with M5 + dowel pins
    Motor OD (6374) directly contacts ball — no separate roller.
    Motor center at 141.5mm from tube axis.
    [connector_ring.stl, flange_ring.stl, frame_half.stl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]
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2026-06-27 monocoque v2: tube ports for motor pass-through
    Key change: 69mm diameter ports in tube wall at each 120° position
    so motor rotor can protrude through and contact ball surface.
    - monocoque_shell: 3 radial ports + motor boss + bridge ribs
    - motor_clamp_cap: arc clamp for motor retention
    - side_plate: matching motor cutouts + bolt holes
    - flange_ring: tube joining ring
    Cleaned old design files (arm/mount/roller/side_plate replaced).
    [connector_flange.stl, frame_main.stl, launch_roller.stl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]
2026-06-27 focus on monocoque_shell: refined single-part design
    Key improvements:
    - 37mm thick tube wall for structural rigidity against launch recoil
    - Port chamfers (outer + inner) to eliminate stress concentration
    - Motor bearing stop on tube inner wall (prevent motor pull-out)
    - Bridge ribs: 1 center + 2 angled (to neighbor cradles) per motor
    - Wire routing channel + M16 grommet hole at bottom
    - M5 bolt + dowel pin flange on each end
    - Split plane along Y axis (avoids motor cradle positions)
    - 10722 faces, ~523KB
    Removed unrelated parts (motor_clamp_cap, side_plate, flange_ring).
    Focus: shell only.
    [flange_ring.stl, monocoque_shell.stl, motor_clamp_cap.stl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]
2026-06-27 monocoque v3: axial motor bolts + cradle length matches motor
    Reference correction from yellow part:
    - 4xM4 bolts are AXIAL (along motor axis), not radial
    - Bolts go through cradle outer end into motor endbell
    - Cradle length = motor length (74mm) + clearance = 82mm
    - Standard BLDC PCD 31mm bolt pattern
    9776 faces, 477KB. Print-friendly with flat end faces.
    [monocoque_shell.stl]
2026-06-27 add tri-motor 6374 v2: outer rotor, motor can through tube wall
    Per PM feedback: motor shaft/can passes through tube wall to contact ball.
    5 parts in cad/3d-print/tri-motor-6374-v2/:
    - launch_tube: monolithic tube, 3 large holes for motor cans, reinforced
    bosses around each hole, 3 bridge ribs between bosses, stiffening rings
    - motor_can: thin-walled can wrapping motor with V-grooves for grip
    - stator_mount: internal stator holder preventing stator rotation
    - bridge_rib: standalone reinforcement (optional)
    Parallel design to monocoque v3 in same parent dir.
    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
    [bridge_rib.stl, launch_tube.stl, motor_can.stl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]
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2026-06-27 v3: add motor cradle (spoked wheel) per reference photo
    Per PM feedback examining reference image:
    - Orange 3D-printed part = independent spoked wheel motor cradle
    (not a tube boss as in v2)
    - Motor axis parallel to tube length (not radial)
    - 4 spokes + outer rim + central hub design
    v3 in cad/3d-print/tri-motor-6374-v3/:
    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
    [bridge_rib.stl, launch_tube.stl, motor_can.stl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]
2026-06-27 v4: integrated spider body (single-piece per reference photo)
    Per PM: build the integrated version matching the yellow reference.
    cad/3d-print/tri-motor-6374-v4/ — 3 parts:
    - spider_body_v4.stl: ONE-PIECE integrated body = center tube segment +
    3 curved Bezier arms + 3 motor cradles. 6266 faces, 306KB
    - motor_can_v4.stl: thin-walled can with V-grooves
    - side_plate_v4.stl: end plate
    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
    [motor_can_v4.stl, side_plate_v4.stl, spider_body_v4.stl]
2026-06-27 v5: integrated body with explicit spoked wheel pattern
    Per PM re-examining reference photo: the orange 3D-printed part has
    a distinctive SPOKED WHEEL pattern (outer rim + 3 spokes + center hub).
    v4 had solid bosses; v5 makes each motor mount a proper spoked wheel.
    cad/3d-print/tri-motor-6374-v5/:
    - spider_body_v5.stl: integrated body = center tube + 3 spoked wheels
    - Each wheel: outer rim ring (10mm wide) + 3 spokes at 120°
    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
    [motor_can_v5.stl, side_plate_v5.stl, spider_body_v5.stl]
2026-06-27 v6: CRITICAL FIX — motor axes now radial (perpendicular to tube)
    PM caught a critical design error: v1-v5 had motor axes parallel to
    tube length, which would only spin the ball in place around the tube
    axis. To simulate football cross/center-pass with spin control, motors
    MUST be perpendicular to the tube (radial).
    cad/3d-print/tri-motor-6374-v6/ — 4 parts:
    - launch_tube_v6.stl: 200mm ball channel (longer for acceleration)
    - motor_cradle_v6.stl: spoked wheel cradle with RADIAL hub axis
    (motor axis points outward from tube center, not along tube)
    - motor_can_v6.stl: radial motor shell with V-grooves
    - side_plate_v6.stl: end plate
    Mechanism:
    - 3 motor cans rotate radially around tube a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
    [launch_tube_v6.stl, motor_can_v6.stl, motor_cradle_v6.stl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]
2026-06-27 v7: refine disc cradle to better match reference photo
    v6 had correct motor axis orientation (radial). v7 refines details:
    - Compact disc-shaped cradle (12mm thick instead of long cylinder)
    - Motor can visibly extends out of cradle toward ball
    - 3 radial spokes at 120° in radial plane
    - 6 M5 mounting holes in outer rim (was 4)
    - Bolt hole visibility improved
    cad/3d-print/tri-motor-6374-v7/ — 4 parts:
    - launch_tube_v7.stl: 180mm ball channel
    - motor_cradle_v7.stl: spoked radial disc with M4 motor mount
    - motor_can_v7.stl: motor shell extending out toward ball
    - side_plate_v7.stl: end plate
    + 2 assembly views (iso/top)
    [launch_tube_v7.stl, motor_can_v7.stl, motor_cradle_v7.stl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]
2026-06-27 v8: single-disc cradle, motor can embedded in tube wall
    Refinements to match reference photo more closely:
    - Single thin disc cradle (8mm) vs v7's 12mm thick disc
    - Motor center now at 125mm (embedded in tube wall) — can actually
    contacts ball surface
    - Cross-shaped groove on can's ball-facing end (visible in reference)
    - Can extends 17.5mm into ball channel for grip
    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
    [launch_tube_v8.stl, motor_can_v8.stl, motor_cradle_v8.stl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]
2026-06-27 v9: fully modular — separate cradles from tube (matches reference)
    Reference photo shows cradles as external bolt-on pieces, not embedded
    in tube wall. v9 returns to fully modular design:
    cad/3d-print/tri-motor-6374-v9/ — 4 parts:
    - launch_tube_v9.stl: tube with 3 large holes for motor cans + 4 internal
    ball guide ribs (keeps ball centered during launch)
    - motor_cradle_v9.stl: external spoked-wheel mount with inner flange that
    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
    [launch_tube_v9.stl, motor_can_v9.stl, motor_cradle_v9.stl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]
2026-06-27 v10: integrated spider body with 180° motor relationship
    Per PM: integrated structure first, modular printing later.
    180° relationship means: motor body on tube exterior + can extends 180°
    opposite through tube wall to contact ball. Motor axis is radial
    (perpendicular to tube), 3 motors at 120°.
    cad/3d-print/tri-motor-6374-v10/ — 3 parts (one big integrated body):
    - spider_body_v10.stl: ONE-PIECE = center tube + 3 spoked-wheel cradles
    + 3 bridge ribs between cradles. 7730 faces, 377KB
    - motor_can_v10.stl: 180°-reversed can (V-grooves + cross groove)
    - side_plate_v10.stl: end plate
    Geometry:
    - Tube: 113mm ID / 140mm OD / 120mm long
    - Motor center: 145mm radius (5mm outside tube wa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
    [motor_can_v10.stl, side_plate_v10.stl, spider_body_v10.stl]
2026-06-27 v11: corrected motor axis — TRUE parallel to tube (was radial in v6-v10)
    PM kept showing the reference photo, which clearly shows the motor axis
    parallel to the tube direction. v6-v10 had motor axis RADIAL (perpendicular
    to tube) — this was wrong.
    v11 corrects the geometry:
    - Motor axis ALONG Z (parallel to tube length)
    - Cradle is a DISC with face perpendicular to Z (visible from end of tube)
    - Hub: cylinder along Z, holds the 6374 motor
    - 3 spokes + outer rim in the XY plane (perpendicular to tube)
    - Can: extends RADIALLY from hub toward ball (180° reversed end of motor)
    This matches the reference photo's visible structure: orange disc-shaped
    cradle with motor mounted inside, can ex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
    [motor_can_v11.stl, side_plate_v11.stl, spider_body_v11.stl]
2026-06-27 v12: scale reference photo proportionally for 6374 + 220mm ball
    Apply 2.5x scale factor to reference image dimensions to fit the
    6374 motor (vs reference 2212) and 220mm football:
    Scale-preserved proportions:
    - Wheel OD = 2.5 × motor OD = 157.5mm
    - Hub OD = 1.15 × motor OD = 72.5mm
    - Disc thickness = 0.25 × motor OD = 15.75mm
    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
    [motor_can_v12.stl, side_plate_v12.stl, spider_body_v12.stl]
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2026-06-27 v14: CORRECTED design — radial motor + flat flywheel disc
    PM caught the fundamental design error: previous designs (v6-v13) had
    motor can rotating around an axis that doesn't produce any Z-direction
    force on the ball. Ball would only spin in place.
    For ball to LAUNCH along tube (Z), the can/flywheel must rotate around
    an axis PERPENDICULAR to Z. Then the contact velocity has Z component:
    v = ω × r = (0, -ω·z_c, ω·y_c)
    v_z = ω·y_c ← Z component exists
    v14 changes:
    - Motor axis along RADIAL direction (X for motor at 0°)
    - Attached FLAT DISC flywheel (not cylindrical shell)
    - Disc face contacts ball tangentially
    - 3 discs at 120° → all v_z components add → ball launche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
    [side_plate_v14.stl, spider_body_v14.stl]
2026-06-28 docs: PROPULSION_ARCHITECTURE_REVIEW_V1 — main direction correction
    PM triggered: stop stacking v15+ visual versions. Lock down propulsion
    mechanism first, then return to CAD.
    Key finding: pure 3-motor radial-tangent layout CANNOT reliably launch
    ball along tube — only spins it in place due to 120° symmetric Z-cancel.
    Three options compared:
    1. Pure 3-rotor friction → ball spins, doesn't translate
    2. Pneumatic primary + 3 motors for spin control → RECOMMENDED main line
    3. Tilted/helical wheel → works but limited speed
    Conclusions:
    - Three motors re-scoped as spin/stability module (not propulsion)
    - Compressed air proposed as primary axial propulsion source
    - Safety envelope de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
2026-06-28 sim: add pneumatic_launch_model + propulsion_source_comparison
    Per PROPULSION_ARCHITECTURE_REVIEW_V1.md mainline conclusion, add
    pneumatic propulsion simulation module.
    New files:
    - sim/pneumatic_launch_model.py
    - Isothermal expansion work model (p0*V0*ln(V_new/V0))
    - MECH_EFFICIENCY=0.30 scaling for friction/leakage losses
    - 6 cases: 5/8 bar, 5/20 L tank, 200/400 mm tube, with curve/topspin variants
    - Safety margin check (8 bar rated)
    - 50 m target reachable: 8 bar / 20 L / 400 mm tube
    - sim/propulsion_source_comparison.py
    - Side-by-side comparison of all 3 options
    - Pure rotor: 13-14 m/s target / 7-10 m range (assumes ideal friction)
    - Pneumatic: 50-90 m/s / 48-80+ m rang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
    [pneumatic_launch_model.py]
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2026-06-28 docs: EML_ALTERNATIVE_V0 — electromagnetic launch feasibility check
    PM query: can electromagnetic launch replace pneumatic?
    Quick answer: technically yes, but P0 not recommended.
    Energy budget for 25 m/s / 430g ball = 134 J KE
    - Coilgun (1-5% eff) → needs 6700 J input
    - LIM/PMLSM (30-60% eff) → needs 225-450 J input
    - Pneumatic (8 bar / 20 L) → 200-500 J effective
    Issues with EML for football:
    1. Mass/size mismatch (430g vs 1-50g typical coilgun projectile)
    2. Capacitor bank danger (>300V, kA)
    3. Wear (no magnetic anchor for non-metallic ball)
    4. Closed-loop control extremely hard
    5. No commercial reference (FORZA / Jug's all pneumatic)
    Conclusion: EML stays as long-term R&D alte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
2026-06-29 v17: tear-down rebuild — monocoque + both-end rib support
    Per owner: tear down past designs, redo per image + requirements.
    Clarified requirements:
    - 90° relationship: stiffening ribs perpendicular to motor axis (end plates)
    - Motor's stationary wire-exit side fixed to ribs at BOTH ends
    - Monocoque shell (not separate arms + cradle)
    - Motor outer can = roller directly (no separate flywheel)
    cad/3d-print/monocoque-v17/ — 2 parts:
    - monocoque_v17.stl: one-piece shell = tube + outer shell + 2 end ribs
    + tube-wall slots for can contact + mid webs. 10626 faces, 518KB
    - side_plate_v17.stl: end plate (pressure/exit)
    Structure:
    - Motor axis parallel to tube (Z)
    - Both motor ends (stator/wi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
    [monocoque_v17.stl, side_plate_v17.stl]
2026-06-30 v18: TANGENT motor axis — correct launch geometry
    Owner correction: 电机轴不平行于管 (motor axis NOT parallel to tube).
    Combined with prior guidance:
    - 恰恰有90度关系 (exactly 90° relationship)
    - 三电机旋转与圆管径向相切 (rotation tangent to tube radial)
    → Motor axis is TANGENTIAL: perpendicular to both the radial direction
    AND the tube Z axis.
    Physics proof (motor at 0°, axis along tangent Y):
    contact point (109,0,0), r=(-31.5,0,0), ω=(0,ω,0)
    v = ω × r = (0,0,31.5ω) → +Z direction = launch direction!
    3 tangent rollers spinning same way → all push ball +Z → ball launches
    by friction drive. Differential speed → curve ball.
    This is the FI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
    [monocoque_v18.stl, side_plate_v18.stl]
2026-06-30 sim: tangent_roller_model — validate v18 geometry
    v18 geometry (3 tangent rollers) physically CAN launch ball along Z.
    This is the first motor-only geometry that produces +Z velocity.
    But quantitative results show PURE TANGENT FRICTION INSUFFICIENT for 50m:
    - 2000 RPM: 2.8 m/s, 0.9m range
    - 2500 RPM: 3.5 m/s, 1.2m range
    - 3000 RPM: 4.9 m/s, 1.8m range
    - 2500 RPM + 60N preload: 5.0 m/s, 1.8m range
    Reason: motor can (63mm) too small vs ball (220mm). Mechanical
    advantage unfavorable — small wheel trying to launch big mass.
    To hit 25 m/s (50m range), need ~18,000 RPM which is far beyond
    6374 spec.
    Validates PM direction (PROPULSION_ARCHITECTURE_REVIEW_V1.md):
    - Compressed air = primary p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
    [tangent_roller_model.py]
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2026-06-30 v20: independent cradle wheels (corrected from v19's continuous shell)
    PM: 你的外圈加强设计并不符合图片 (your outer ring reinforcement
    doesn't match the picture).
    Reference photo shows:
    - Individual cradle wheels (not continuous outer shell)
    - Each wheel has thick outer RIM (reinforcement), 3 spokes, center hub
    - 4×M5 bolts fix wheel rim to tube
    v19 had continuous outer shell — wrong structure.
    v20: 3 independent cradle wheels (each matching reference).
    cad/3d-print/independent-wheels-v20/ — 3 parts (3 wheels + 1 tube + 2 plates):
    - cradle_wheel_v20.stl: rim OR 160.5mm, IR 115.5mm, thick 14mm
    + 3 spokes + center hub + 4×M5 bolts. 4202 faces.
    - tube_v20.stl: simple tu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
    [cradle_wheel_v20.stl, monocoque_v19.stl, side_plate_v19.stl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]
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2026-07-01 v23: control panel V1 — single-page HTML interactive prototype
    PM: 我接可实现 HTML 面板 V1，不再做散图。
    验收: 不是图片，是能进入前端实现的 UI 规格 + mock 交互原型.
    Delivered: cad/3d-print/control-panel-v23/control_panel_v1.html
    (40 KB, 1163 lines, single file with embedded CSS/JS)
    4 Tabs:
    - 首页 (Home): mode selection (6 buttons) + launch readiness
    + launch controls (launch/test/lock/unlock/estop)
    - 弧线 (Arc): predicted vs actual SVG trajectory
    + landing data + deviation analysis + refill params
    - 参数 (Params): 3 motor RPM sliders + pressure/valve/piston
    + curve/spin strength + confirm/save/reset
    - 诊断 (Diag): system overview + error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
2026-07-01 v24: control panel upgraded to HIFI_SPEC_V1 spec
    Per designer DISPLAY_UI_HIFI_SPEC_V1, upgraded control panel:
    Colors (HIFI §2):
    - bg #080B0F/#121821/#1B2430
    - text #F4F7FA/#AAB4C0/#6F7A86
    - status #21C55D/#FACC15/#EF4444
    - trajectory #38BDF8/#FB923C
    Layout (HIFI §1): 56px top + 472px main + 72px bottom (incl. tabs)
    Components (HIFI §4):
    - Status cards with 6px left status bar
    - Mode buttons: default/active(blue)/pending(yellow)/disabled
    - Sliders: yellow when pending
    - Emergency bar: fixed bottom, never covered
    - Trajectory legend: 4 elements distinct
    - Error cards: yellow/red banner
    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
2026-07-01 docs: resolve structural BLOCKERs — owner confirmed parameters
    - Transmission: 6374 outer rotor direct drive
    - Center channel: standard size-5 football
    - Materials: determined by structural strength requirements
    - Update roadmap BLOCKER section to resolved status
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2026-07-02 feat: add PlatformIO build system + fix compilation issues
    - Add platformio.ini for host (ESP32-S3) and node (B-G431B-ESC1)
    - Fix host_state.h: add missing sensor/telemetry fields for feed controller
    - Fix host_hal.h: add missing feed function declarations
    - Fix host_hal_stub.cpp: add stub implementations for feed functions
    - Fix host_hal_espidf_twai.cpp: add feed function stubs
    - Fix host app_main.cpp: remove break in while loop, rename main to app_entry
    - Fix node app_main.cpp: remove break in while loop
    - Add main_bridge.cpp for Arduino framework compatibility
    - Update .gitignore for PlatformIO artifacts and build symlinks
    Build verification: both targets compile successfully.
    Host: 16 s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
    [app_main.cpp, host_hal_espidf_twai.cpp, host_hal_stub.cpp]
2026-07-02 feat: Phase 0/1 real HAL implementations (stub-switchable)
    Phase 0 — ESP32-S3 Host HAL (host_hal_espidf_real.cpp):
    - ESP-IDF TWAI CAN 500kbps init/send/recv
    - GPIO input for 5 sensors (ball/tube/chamber/exit/estop)
    - GPIO output for launch trigger, feed actuator, LED, buzzer
    - esp_timer 1ms tick
    - Pin map: TWAI TX=GPIO5 RX=GPIO4, sensors GPIO6/7/15/16/17
    Phase 1 — STM32G431 Node HAL (node_hal_stm32_real.cpp + hw_init.cpp):
    - FDCAN 500kbps init/send/recv (PA11/PA12)
    - TIM1 3-phase complementary PWM 20kHz with dead time
    - ADC single-shot for VBUS/temperature
    - GPIO: DRV_EN (PB12), DRV_FAULT_N (PB11), Hall A/B/C (PB6/7/8)
    - NTC thermistor temperature calculation
    Build system: both targets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
    [host_hal_espidf_real.cpp, hw_init.cpp, node_hal_stm32_real.cpp]
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2026-07-02 docs: correct spin direction — each motor pushes ball toward exit
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2026-07-02 docs: lock structural design — motor axis perpendicular to tube axis, radial mounting
    - Motor axis ⊥ tube axis (radial)
    - Stator fixed outside tube wall
    - Outer rotor can embedded in tube wall
    - Rotor surface tangential velocity parallel to tube axis → natural forward spin
    - View along tube axis: center circle = ball, 3 rectangles = motor cross-sections at 120°
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2026-07-03 docs: lock final spin unit structure
    - One-piece tube + 3 radial arms (perpendicular to tube axis)
    - Motor fixed on arm tip: circular end face 4×M4 (45mm spacing)
    - Rotor can (smooth cylinder) extends through tube window to contact ball
    - 3 motors same rotation direction → forward spin
    - Differential speed → curve ball
    - Reference: thisismax B-G431B-ESC1 + Bluey Blaster
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2026-07-10 docs: correct motor layout constraints per owner feedback
    Key corrections:
    - Motor shaft lines do NOT point toward tube center (tangential offset)
    - Center circle = launch tube (not ball in inscribed position)
    - Force decomposition: normal (clamping) + tangential (driving)
    - Tangential offset is the source of ball rotation/velocity
    - Added offset angle consistency check to CAD verification
2026-07-10 docs: add motor end-face design constraints
    - Fixed end: 4-screw mounting plate (matches 6374 flange holes)
    - Rotating end: non-contact protective guard (safety clearance)
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2026-07-10 docs: rewrite spin unit structure — motor axes form equilateral triangle, rotor cylinder contacts ball
    - Motor axes point toward tube center (radial inward) but don't pass through center
    - Axis extensions form equilateral triangle, ball at inscribed position
    - Outer rotor cylindrical surface (max rotating face) contacts ball through tube wall
    - Motor end faces face outward, mounted to bracket
    - 6374 has 4(8) screw holes on end face
    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
2026-07-10 docs: correct motor layout - shaft lines cross pairwise (not star/radial)
    Owner correction: shaft extension lines cross each other pairwise,
    crossing points = equilateral triangle vertices. Motors are at
    midpoints of triangle sides, NOT at vertices. This is fundamentally
    different from the radial/star pattern previously drawn.
2026-07-11 docs: correct to triangle structure (not crossing, not star)
    Owner correction: motors are at vertices of equilateral triangle,
    shaft extension lines connect adjacent motors (= triangle sides).
    This is a triangle structure, not star or crossing pattern.
2026-07-11 docs: correct geometry to triangle structure
    - 3 motors at equilateral triangle VERTICES (not midpoints)
    - Each motor axis extends toward next motor = triangle edges
    - Launch tube at center, axes pass through tube cylinder
    - NOT star/radial, NOT crossing - triangle structure
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
